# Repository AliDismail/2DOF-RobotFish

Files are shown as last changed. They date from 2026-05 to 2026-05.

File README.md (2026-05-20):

# 2-DoF Fish Robot - Kinematics Project

Robotic fish have attracted significant attention for their biomimetic design and applications in environmental monitoring, biological surveys, and underwater exploration. Unlike propeller-driven systems, which generate noise and disturb marine ecosystems, robotic fish provide efficient and less intrusive locomotion.

This project builds on the work of Wang et al. (2026) by focusing on the kinematic modeling of a wire-driven fish equipped with a 2-DoF crank-slider mechanism. The design decouples propulsion from steering, enabling both high swimming speed and agile maneuverability. While the original study employed servo-based continuous rotation control, our project simplifies the system using budget-friendly components and replaces the motor control with an encoder-based PID algorithm. This ensures smooth, accurate motion while retaining the core crank-slider actuation and robotic system architecture.

---

## Table of Contents

- [Design Analysis](#design-analysis)
  1. [Original Design Concept from the Research Paper](#1-original-design-concept-from-the-research-paper)
  2. [Description of the SolidWorks Design](#2-description-of-the-solidworks-design)
  3. [Mechanism Type and Degree of Freedom](#3-mechanism-type-and-degree-of-freedom)
  4. [Kinematic Analysis](#4-kinematic-analysis)
  5. [Material Selection](#5-material-selection)
  6. [Limitations of the Current Design](#6-limitations-of-the-current-design)
  7. [Conclusion](#7-conclusion-design-analysis)
- [Motion Control](#motion-control)
  - [Methodology and Implementation](#methodology-and-implementation)
- [Hardware and Programming Implementation](#hardware-and-programming-implementation)
- [Conclusion](#conclusion)
- [References and Links](#references-and-links)

---

## Design Analysis

In this section, we analyze the Biomimetic Fish Robot Based on a Modified 2-DoF Crank-Slider / Slotted Crank-Rocker Mechanism.

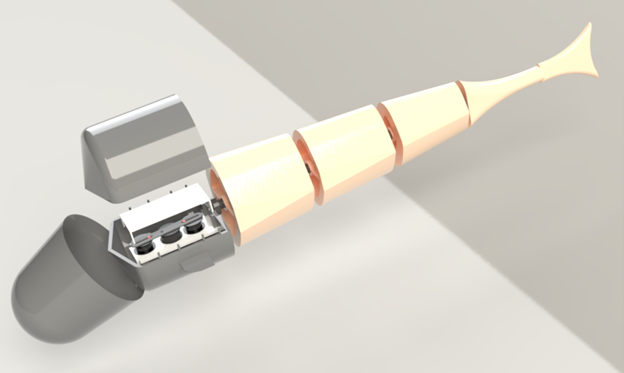
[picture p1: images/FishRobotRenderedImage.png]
Figure 1: FishRobotRenderedImaget


_Figure 1: Fish Robot Rendered Image_

### 1. Original Design Concept from the Research Paper

The original robotic fish consists of a rigid head shell, segmented rear body, elastic spine, driving wire, pectoral fins, and passive caudal fin. The rigid head contains the actuation mechanism and electronics, while the rear body bends to generate fish-like swimming motion.

The actuation mechanism in the paper contains two independently controlled driving wheels connected to a slotted rod and reel. The reel drives a wire connected to the tail. The main advantage of the mechanism is that it can operate in symmetric and asymmetric modes. In symmetric mode, both motors rotate together to produce forward propulsion. In asymmetric mode, one motor can create a mean tail offset while the other provides continuous oscillation, allowing turning motion.

The original prototype used compact DYNAMIXEL servo motors, a PLA body and head, SUS304 stainless steel linkage components, a silicone waterproof skin, and an elastic urethane spine. The paper reports that the prototype was 502 mm long, 83 mm wide, 128 mm high, and had a mass of 2050 g.

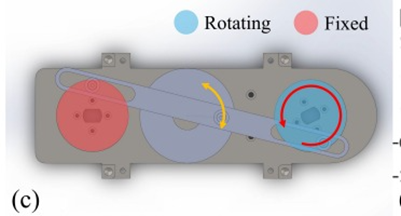
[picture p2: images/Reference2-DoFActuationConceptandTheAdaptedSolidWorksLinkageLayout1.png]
Figure 2: Reference2-DoFActuationConceptandTheAdaptedSolidWorksLinkageLayout1

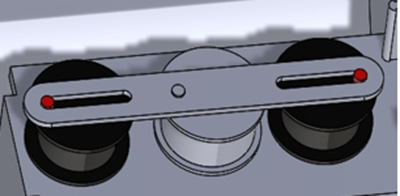
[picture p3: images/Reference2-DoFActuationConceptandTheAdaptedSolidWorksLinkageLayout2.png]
Figure 2.5: Reference2-DoFActuationConceptandTheAdaptedSolidWorksLinkageLayout2

_Figure 2: Reference 2-DoF Actuation Concept and The Adapted SolidWorks Linkage Layout_

### 2. Description of the SolidWorks Design

The SolidWorks model follows the same general fish structure as the paper but includes important changes to fit the available components. The design contains a deeper front tub, internal gears, DC motors, a slotted rocker linkage, segmented cylindrical body parts, and a tail fin. The main design focus was packaging the actuation mechanism inside the head while maintaining the external appearance of a fish.

The head tub is the main mechanical housing. It supports the motors, gears, shafts, rocker link, and cover. Since the DC motors used in this project are much taller than the servo motors in the original paper, the tub had to be significantly deeper. This modification allowed the motors to fit vertically while leaving enough clearance for the gears and moving linkage.

The final SolidWorks model has an overall length of 1051 mm, a maximum width of 190 mm, and a maximum height of 159 mm. These dimensions represent the complete assembled fish robot, including the rigid head, internal motor tub, segmented body, and caudal fin. Compared with the original paper, the overall dimensions are larger mainly because our design uses taller DC motors with encoders, which require a deeper head section to fit the motors, gears, and linkage mechanism.

The rear body was modeled as multiple streamlined segments to represent the flexible body of the fish. The caudal fin was modeled at the rear to represent the tail surface responsible for producing thrust when oscillated.

### 3. Mechanism Type and Degree of Freedom

The mechanism in the SolidWorks design is best described as a double-input slotted crank-rocker mechanism inspired by the paper's 2-DoF crank-slider system. The rotating gears or disks act as cranks. The pins on these gears slide inside elongated slots in the long central link. This long link does not rotate continuously through 360 degrees; instead, it oscillates through a limited angle. Therefore, it behaves like a rocker.

The rocker type used in this design is a slotted rocker. It is "slotted" because the crank pins move inside long slots, and it is a "rocker" because its output is limited to angular oscillation rather than full rotation.

The output of the rocker is transmitted to the elastic tail through a driving wire. One end of the wire is fixed to the reel, which is attached to the central rocker link, and the other end is fixed to the trailing section of the elastic spine. As the rocker oscillates, it winds and unwinds the wire alternately, pulling the tail from side to side and generating the oscillatory body motion required for propulsion. The wire offset distance _d_ from the spine centerline converts the reel's angular displacement directly into the tail attack angle θₐ.

In its complete actuated form, the system has two actuated degrees of freedom because it uses two independently driven motors. The motors are independently controlled — one input can affect oscillation frequency and the other can affect the mean tail angle. However, if both motors are synchronized or if one motor is fixed while the other rotates, the mechanism behaves as an effective 1-DOF mechanism during that operating condition.

The degrees of freedom of the mechanism are verified using the Kutzbach criterion:

$$M = 3(n - 1) - 2j_1 - j_2$$

where _n_ is the number of links, _j₁_ is the number of full joints (one degree of freedom each), and _j₂_ is the number of half joints (two degrees of freedom each). The mechanism consists of 5 links: the ground frame, the two driving cranks (gear disks), middle gear, and the central slotted rocker. It has 4 full joints: the two revolute joints at the motor shafts and the two pin-in-slot joints between the crank pins and the rocker slots.

Substituting:

$$M = 3(5 - 1) - 2(4) - 1(2) = 12 - 8 - 2 = 2$$

When one motor is set to a bias angle:

$$M = 3(4 - 1) - 2(3) - 1(2) = 1$$

Hence the system has **2 DoF in symmetric mode** and **1 DoF in asymmetric mode**.

### 4. Kinematic Analysis

The purpose of the internal mechanism is to convert motor rotation into oscillating tail motion. Each motor rotates a gear or disk with an offset pin. As the disk rotates, the pin follows a circular path. Since the pin is located inside a slot in the rocker, the circular motion forces the rocker to oscillate.

The operating sequence is as follows:

1. DC motors rotate the gears.
2. The gear pins move inside the rocker slots.
3. The rocker oscillates from side to side.
4. This oscillation is transmitted to the tail.

The resulting tail motion imitates the left-right tail beat of a swimming fish.

When both motors rotate together, the mechanism produces a more symmetric oscillation suitable for forward swimming. When one motor position is shifted or fixed while the other rotates, the output becomes biased to one side. This creates a mean tail angle and can be used for turning.

### 5. Material Selection

For a prototype, the head tub and body sections are manufactured using PLA because it is easy to 3D print and suitable for rapid prototyping.

For the linkage and rocker, a stronger material such as aluminum or stainless steel is preferred because these parts experience sliding contact and repeated oscillating loads. The original paper used SUS304 stainless steel for the actuation linkage, which provides good strength and corrosion resistance. Our project uses a 3D printed link due to a tight schedule.

The spine should be made from a flexible material such as rubber, silicone, TPU, or another compliant polymer.

**Table 1: Selected Part Material**

| Part | Suggested Material | Reason |
| --- | --- | --- |
| Head tub / rigid shell | PLA | Easy to 3D print, rigid, suitable for prototypes  |
| Body segments | PLA | Lightweight and simple to manufacture |
| Slotted rocker / linkage | Aluminum or SUS304 stainless steel | Higher stiffness and better wear resistance |
| Gear shafts | Steel or stainless steel | Good strength and alignment stability |
| Spine | TPU, rubber, or silicone | Flexible and suitable for oscillating tail motion |

### 6. Limitations of the Current Design

The main limitation is the large head depth caused by using tall DC motors, making the design less compact than the original and potentially reducing swimming efficiency due to increased drag.

Although the design uses DC motors equipped with encoders (which improves motion feedback), the servo motors used in the original are more accurate.

The slotted rocker mechanism may also experience friction and wear at the sliding contacts. Bearings, bushings, or low-friction inserts could improve the motion.

### 7. Conclusion (Design Analysis)

The SolidWorks model successfully recreates the main mechanical concept of the robotic fish presented in the reference paper. The design uses a double-input slotted crank-rocker mechanism inspired by the 2-DoF crank-slider actuation system. The mechanism converts rotary input from two motors into an oscillating rocker motion that can be transferred to the tail.

The largest design difference is the actuator selection. The original research prototype used compact servo motors, while this project used taller DC motors, requiring a much deeper head tub. The mechanism has 2 actuated degrees of freedom when both motors are independently controlled, but can behave as an effective 1-DOF mechanism when synchronized. Future improvements are needed in compactness, waterproofing, friction reduction, and motion validation.

---

## Motion Control

### Methodology and Implementation

The fish robot is designed based on a biomimetic actuation mechanism that converts rotational motor inputs into oscillatory tail motion. The system consists of two motor-driven cranks connected to a reel through linkages, forming a crank–slider mechanism. This configuration enables controlled deformation of a flexible tail, which generates propulsion through periodic motion (Lee et al., 2007).

Please find the detailed implementation and derivationm in the detailed report of the project.

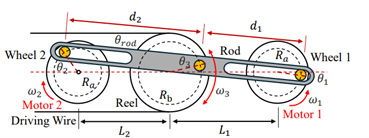
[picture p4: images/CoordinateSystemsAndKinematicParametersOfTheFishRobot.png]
Figure 3: CoordinateSystemsAndKinematicParametersOfTheFishRobot


_Figure 3: Coordinate Systems And Kinematic Parameters Of The Fish Robot_

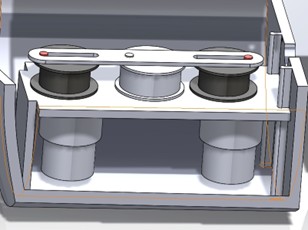
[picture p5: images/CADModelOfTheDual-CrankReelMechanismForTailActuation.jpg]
Figure 4: CADModelOfTheDual-CrankReelMechanismForTailActuation


_Figure 4: CAD Model Of The Dual-Crank Reel Mechanism For Tail Actuation_

The sign of φ (the pitch angle between the the tip of the tail and the horizental line) determines the direction of turning:

| φ value | Effect |
| --- | --- |
| φ < 0 (e.g., −π/2) | Tail biased right → robot turns right |
| φ > 0 (e.g., +π/2) | Tail biased left → robot turns left |
| φ = 0 | Reduces to symmetric case → robot swims straight |

This is consistent with the paper's experimental result, where fixing Motor 2 at −90° produced a turning radius of 0.56 m (1.12 BL), completing one full circle in 14 seconds.

---

## Hardware and Programming Implementation

### Hardware

The following components were used for the implementation:

- Arduino Nano 3.0
- Dual Channel DC Motor Driver L298N
- DC Motor with Gearbox and Encoder JGB37-520 12V 178RPM
- LiPo Battery 3S 30C 1800mAh
- 3S LiPo Battery Balance Charger
- 12V to 5V Voltage Converter

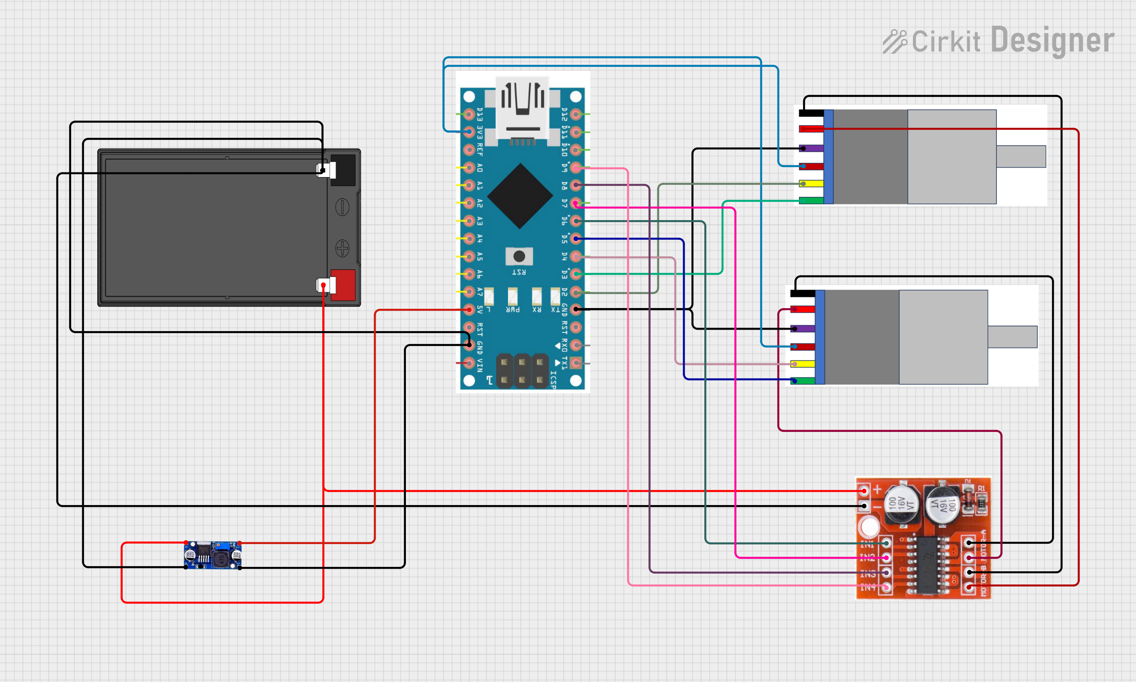
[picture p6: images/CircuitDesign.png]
Figure 5: CircuitDesign


_Figure 5: Circuit Design_

### Programming and Control Algorithm

The control algorithm is implemented on an Arduino Nano 3.0 and structured around a fixed 20 Hz interrupt-driven loop. The system reads both motor encoders at each tick, computes forward kinematics, and updates the motor controllers accordingly.

#### 1. Encoder Feedback

Each JGB37-520 motor is equipped with a Hall effect encoder rated at 20 pulses per revolution (PPR). Quadrature decoding is applied by monitoring both encoder channels on interrupt pins, yielding an effective resolution of 80 counts per revolution. From the encoder count delta over the control period ΔT:

```
θ = (counts / 80) · 2π
ω = Δcounts / (80 · ΔT) · 2π
```

#### 2. Motor 1 with Speed PID

The kinematic model treats the angular velocity of Motor 1 as a constant input ω. To enforce this at the hardware level, Motor 1 is governed by a single-loop speed PID:

```
error₁ = ω_target − ω_measured
```

The output drives the L298N PWM signal such that the measured angular velocity tracks the commanded tail-beat frequency regardless of load variation.

#### 3. Motor 2 with Cascaded Position–Speed PID

Motor 2 must hold a fixed angular position φ during asymmetric mode while the elastic spine continuously exerts a restoring torque against it. A cascaded (inner–outer) PID structure is used.

The outer loop operates on position error and outputs a commanded angular velocity:

```
error_pos = φ_target − φ_actual
ω_commanded = PID_outer(error_pos)
```

The inner loop then tracks that commanded velocity in real time:

```
error_spd = ω_commanded − ω_measured
PWM = PID_inner(error_spd)
```

This structure makes the holding behavior stiff — the inner loop actively drives the motor at whatever rate the outer loop requires, counteracting the tail load before significant position error accumulates.

#### 4. Control Modes and Sequence

The system operates in two modes:

- **Symmetric mode:** Both motors are commanded to rotate at ω speed, and Motor 2's position setpoint mirrors Motor 1's live encoder reading.
- **Asymmetric mode:** Motor 1's speed PID maintains ω while Motor 2's cascaded PID holds φ at the steering offset.

The demo sequence cycles continuously through:

> Forward swimming (3 s) → Right turn (1 s) → Forward (1 s) → Left turn (1 s)

All PID integrators are reset at each mode transition to prevent windup carry-over.

---

## References and Links

- Wang, Y., Chen, C., Chen, Y., Li, J., Motegi, Y., Ohkuma, K., Maki, T., & Zhao, M. (2026). _Design, modeling and direction control of a wire-driven robotic fish based on a 2-DoF crank-slider mechanism_. arXiv. <https://arxiv.org/abs/2603.02851>

- Lee, S., Park, J., & Han, C. (2007). Optimal control of a mackerel-mimicking robot for energy efficient trajectory tracking. _Journal of Bionic Engineering_, 4(4), 209–215. <https://doi.org/10.1016/S1672-6529(07)60029-7>

---

**Done by** Ali Ismail, Maria Al Sayed, Ghadi Ammar, and Elie Mina

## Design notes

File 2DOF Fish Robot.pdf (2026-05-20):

# Lebanese American University

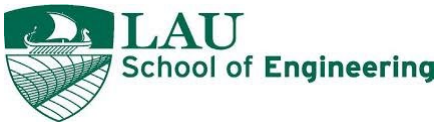
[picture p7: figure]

# MEE 342 – Kinematics of Machines

# Dr. Carine Habchi

# Kinematics Project

### Maria Al Sayed Ghadi Ammar Ali Ismail Elie Mina

04-08-2026

[Al Sayed, Ammar, Ismail, & Mina]

# Table of Contents

# Table of Tables

# Table of Figures

Figure 2: Reference 2-DoF Actuation Concept and The Adapted SolidWorks Linkage Layout .........Error! Bookmark not defined.

# Introduction

Robotic fish have attracted significant attention for their biomimetic design and applications in environmental monitoring, biological surveys, and underwater exploration. Unlike propeller-driven systems, which generate noise and disturb marine ecosystems, robotic fish provide efficient and less intrusive locomotion. This project builds on the work of Wang et al. (2026) by focusing on the kinematic modeling of a wire-driven fish equipped with a 2-DoF crank-slider mechanism. The design decouples propulsion from steering, enabling both high swimming speed and agile maneuverability. While the original study employed servo-based continuous rotation control, our project simplifies the system using budget-friendly components and replaces the motor control with an encoder based PID algorithm. This ensures smooth, accurate motion while retaining the core crank-slider actuation and robotic system architecture.

# Design Analysis

In this section, we will go through the analysis of the Biomimetic Fish Robot Based on a Modified 2-DoF Crank-Slider / Slotted Crank-Rocker Mechanism.

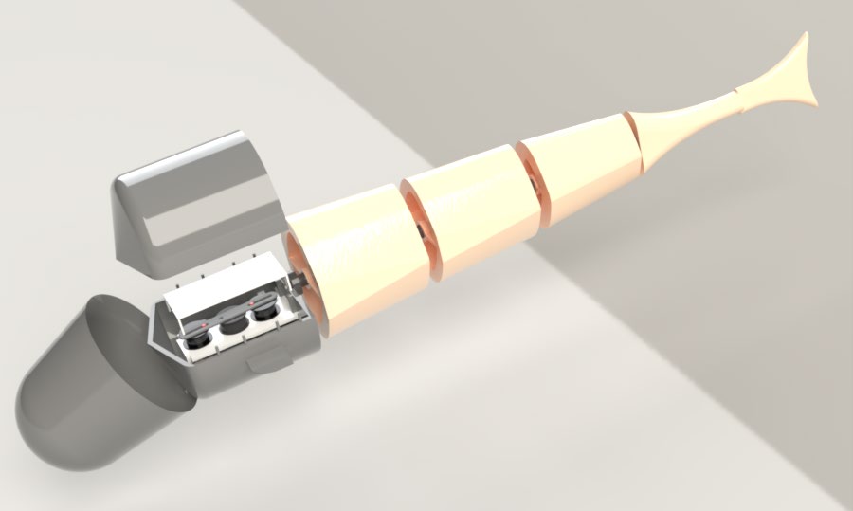
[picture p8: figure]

Figure 1: Fish Robot Rendered Image

## 1. Original Design Concept from the Research Paper

The original robotic fish consists of a rigid head shell, segmented rear body, elastic spine, driving wire, pectoral fins, and passive caudal fin. The rigid head contains the actuation mechanism and electronics, while the rear body bends to generate fish-like swimming motion.
The actuation mechanism in the paper contains two independently controlled driving wheels connected to a slotted rod and reel. The reel drives a wire connected to the tail. The main advantage of the mechanism is that it can operate in symmetric and asymmetric modes. In symmetric mode, both motors rotate together to produce forward propulsion. In asymmetric mode, one motor can create a mean tail offset while the other provides continuous oscillation, allowing turning motion.
The original prototype used compact DYNAMIXEL servo motors, a PLA body and head, SUS304 stainless steel linkage components, a silicone waterproof skin, and an elastic urethane spine. The paper reports that the prototype was 502 mm long, 83 mm wide, 128 mm high, and had a mass of 2050 g.

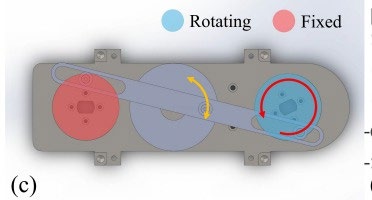
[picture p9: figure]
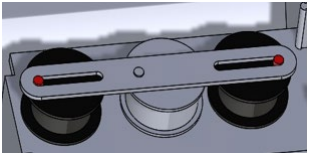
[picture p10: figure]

Figure 2: Reference 2-DoF Actuation Concept and The Adapted SolidWorks Linkage Layout

## 2. Description of the SolidWorks Design

The SolidWorks model follows the same general fish structure as the paper but includes important changes to fit the available components. The design contains a deeper front tub, internal gears, DC motors, a slotted rocker linkage, segmented cylindrical body parts, and a tail fin. The main design focus was packaging the actuation mechanism inside the head while maintaining the external appearance of a fish.
The head tub is the main mechanical housing. It supports the motors, gears, shafts, rocker link, and cover. Since the DC motors used in this project are much taller than the servo motors in the original paper, the tub had to be significantly deeper. This modification allowed the motors to fit vertically while leaving enough clearance for the gears and moving linkage.

The final SolidWorks model has an overall length of 1051 mm, a maximum width of 190 mm, and a maximum height of 159 mm. These dimensions represent the complete assembled fish robot, including the rigid head, internal motor tub, segmented body, and caudal fin. Compared with the original paper, the overall dimensions are larger mainly because our design uses taller DC motors with encoders, which require a deeper head section to fit the motors, gears, and linkage mechanism.

The rear body was modeled as multiple streamlined segments to represent the flexible body of the fish. The caudal fin was modeled at the rear to represent the tail surface responsible for producing thrust when oscillated.

## 3. Mechanism Type and Degree of Freedom

The mechanism in the SolidWorks design is best described as a double-input slotted crank-rocker mechanism inspired by the paper's 2-DoF crank-slider system. The rotating gears or disks act as cranks. The pins on these gears slide inside elongated slots in the long central link. This long link does not rotate continuously through 360 degrees; instead, it oscillates through a limited angle. Therefore, it behaves like a rocker.
The rocker type used in this design is a slotted rocker. It is "slotted" because the crank pins move inside long slots, and it is a "rocker" because its output is limited to angular oscillation rather than full rotation. The output of the rocker is transmitted to the elastic tail through a driving wire. One end of the wire is fixed to the reel, which is attached to the central rocker link, and the other end is fixed to the trailing section of the elastic spine. As the rocker oscillates, it winds and unwinds the wire alternately, pulling the tail from side to side and generating the oscillatory body motion required for propulsion. The wire offset distance d from the spine centerline converts the reel's angular displacement directly into the tail attack angle θₐ.
In its complete actuated form, the system has two actuated degrees of freedom because it uses two independently driven motors. The motors are independently controlled, one input can affect oscillation frequency and the other can affect the mean tail angle. However, if both motors are synchronized or if one motor is fixed while the other rotates, the mechanism behaves as an effective 1-DOF mechanism during that operating condition.
The degrees of freedom of the mechanism are verified using the Kutzbach criterion:
M = 3(n − 1) − 2j₁ − j₂
where n is the number of links, j₁ is the number of full joints (one degree of freedom each), and j₂ is the number of half joints (two degrees of freedom each). The mechanism consists of 5 links: the ground frame, the two driving cranks (gear disks), middle gear, and the central slotted rocker. It has 4 full joints: the two revolute joints at the motor shafts and the two pin-in-slot joints between the crank pins and the rocker slots. The pin-in-slot joint allows both rotation and sliding simultaneously, making it a full joint with 2 relative motions, which counts as a half joint j₂ in the Kutzbach formula. Substituting:
M = 3(5 − 1) − 2(4) − 1(2) = 12 − 8 − 2 = 2 This gives M = 2 for a dual-input system. When we set one of the motors on a bias angle. The mechanism therefore has:
M = 3(4 − 1) − 2(3) − 1(2) = 1 Hence the system will have 2 DoF in symmetric mode and 1 DoF in asymmetric mode.

## 4. Kinematic Analysis

The purpose of the internal mechanism is to convert motor rotation into oscillating tail motion. Each motor rotates a gear or disk with an offset pin. As the disk rotates, the pin follows a circular path. Since the pin is located inside a slot in the rocker, the circular motion forces the rocker to oscillate.

The operating sequence is the DC motors rotate the gears, the gear pins move inside the rocker slots, the rocker oscillates from side to side, and this oscillation can be transmitted to the tail. The resulting tail motion imitates the left-right tail beat of a swimming fish.
When both motors rotate together, the mechanism produces a more symmetric oscillation suitable for forward swimming. When one motor position is shifted or fixed while the other rotates, the output becomes biased to one side. This creates a mean tail angle and can be used for turning.

## 5. Material Selection

For a prototype, the head tub and body sections are manufactured using PLA because it is easy to 3D print and suitable for rapid prototyping.
For the linkage and rocker, a stronger material such as aluminum or stainless steel is preferred because these parts experience sliding contact and repeated oscillating loads. The original paper used SUS304 stainless steel for the actuation linkage, which is suitable because it provides good strength and corrosion resistance. But we have a 3D printed link due to a tight schedule.
The spine should be made from a flexible material such as rubber, silicone, TPU, or another compliant polymer. Table 1 summarizes the suggested material choices for the main parts of the design.

Table 1: Selected Part Material
Part | Suggested Material | Reason
Head tub / rigid shell | PLA | Easy to 3D print, rigid, suitable for prototypes
Body segments | PLA | Lightweight and simple to manufacture
Slotted rocker / linkage | Aluminum or SUS304 stainless steel | Higher stiffness and better wear resistance
Gear shafts | Steel or stainless steel | Good strength and alignment stability
Spine | TPU, rubber, or silicone | Flexible and suitable for oscillating tail motion

## 6. Limitations of the Current Design

The main limitation is the large head depth caused by using tall DC motors. This makes the design less compact than and may reduce swimming efficiency due to increased drag.
Another limitation is that although the design uses DC motors, they are equipped with encoders, which improves motion feedback and allows the motor position and speed to be monitored. This makes the system more controllable than a basic DC motor setup. However, the servo motors used in the original are more accurate.
The slotted rocker mechanism may also experience friction and wear at the sliding contacts. Bearings, bushings, or low-friction inserts could improve the motion.

## 7. Conclusion

The SolidWorks model successfully recreates the main mechanical concept of the robotic fish presented in the reference paper. The design uses a double-input slotted crank-rocker mechanism inspired by the 2-DoF crank-slider actuation system. The mechanism converts rotary input from two motors into an oscillating rocker motion that can be transferred to the tail.
The largest design difference is the actuator selection. The original research prototype used compact servo motors, while this project used taller DC motors. Because of this, the head tub had to be made much deeper to fit the motors, gears, shafts, and linkage. This caused the final dimensions of the design to differ significantly from the original paper.
The mechanism can be described as having 2 actuated degrees of freedom when both motors are independently controlled. However, it can behave as an effective 1 DOF mechanism when the motors are synchronized or when one motor is fixed. Overall, the design demonstrates a practical mechanical adaptation of the paper’s fish robot concept, with future improvements needed in compactness, waterproofing, friction reduction, and motion validation.

# Motion Control

## Methodology and Implementation

### 1. System Overview

The fish robot is designed based on a biomimetic actuation mechanism that converts rotational motor inputs into oscillatory tail motion. The system consists of two motor-driven cranks connected to a reel through linkages, forming a crank–slider mechanism. This configuration enables controlled deformation of a flexible tail, which generates propulsion through periodic motion (Lee et al., 2007).

### 2. Forward Kinematics Derivation

The objective of forward kinematics is to compute the reel angle θθ3from the known motor angles θθ1and θθ2.

Coordinate Representation
The positions of the mechanism components are defined as:
xx1 = Ra cos θθ1 + LL1 + LL2, yy1 = Ra sin θθ1 | (1)
xx2 = Ra cos θθ2 , yy2 = Ra sin θθ2 | (2)
xx3 = Rb cos θθ3 + LL2, yy3 = Rb sin θθ3 | (3)

Collinearity Constraint
The linkage points must remain collinear:

# yy2 − yy3 xx2 − xx3

# = yy1 − yy3 xx1 − xx3

(4)

Substituting:

# RRaasin θθ2 − RRbbsin θθ3

# RRaacos θθ2 − (RRbbcos θθ3 + LL2) = RRaasin θθ1 − RRbbsin θθ3 (RRaacos θθ1 + LL1 + LL2) − (RRbbcos θθ3 + LL2) (5)

Rearranged Form

By expanding Eq. (5) and grouping terms involving sin θθ3and cos θθ3, the expression can be rearranged

into a linear trigonometric form. After expansion and simplification using trigonometric identities, the equation is reduced to:

# AA cos θθ3 + BB sin θθ3 = CC (6)

where:

A = RaRb(cos θθ1 − cos θθ2) + Rb(LL1 + LL2) | (7)
BB = RRaaRRbb(sin θθ2 − sin θθ1) | (8)

# CC = RRaa

# 2 sin(θθ1 − θθ2) − RRaa(sin θθ1LL2 + sin θθ2LL1) (9)

Closed-Form Solution

# θθ3 = arcsin CC

# √AA2+BB2 − atan 2(BB, AA) (10)

This transformation allows the nonlinear geometric constraint to be solved analytically using trigonometric identities, avoiding iterative numerical methods, in addition it allows direct computation of the reel angle, making it suitable for real-time embedded implementation (Lee et al., 2007).

### 3. Tail Kinematics

The tail is modeled as a constant curvature arc:

# θa = Rb

dd θθ3 | (11)

# xx = LL

θθaa

# sin θθaa , yy = LL

θθaa

# (1 − cos θθaa) (12)

For small θθaa, a linear approximation is used to maintain numerical stability.

### 4. Implementation

The analytical model was implemented on an embedded system using Arduino. The forward kinematics equations are directly translated into code:

A validity check ensures that the computed configuration is physically feasible:

The tail position is computed as:

### 5. Velocity Estimation and Propulsion

The reel angular velocity is approximated numerically:
θθ̇

# 3 ≈ θθ3(tt) − θθ3(tt − Δtt)

Δtt | (13)

The tail-tip lateral velocity is computed using:

# vvtip =∣

LL
θθaa

# 2 (sin θa − θa cos θa)θ̇

aa ∣ (14)

The swimming speed is then estimated using a proportional model:

# vvrobot = kkthrust ⋅ vvtip (15)

### 6. Results and Interpretation

The implementation produces periodic oscillatory motion of the tail, resulting in a stable forward swimming velocity. The symmetric mode generates balanced lateral motion, confirming that the robot moves in a straight line without directional bias.
The results demonstrate that the derived kinematic model is consistent with the expected behavior of a biomimetic fish robot.

### 7. Discussion

The model successfully integrates kinematics and motion generation; however, several simplifications are present:
- Hydrodynamic effects are not explicitly modeled
- The propulsion model is simplified and experimentally tuned
- The tail is approximated as a constant curvature arc
- Numerical differentiation introduces approximation error
Despite these limitations, the model provides a computationally efficient framework for simulating robotic fish motion.

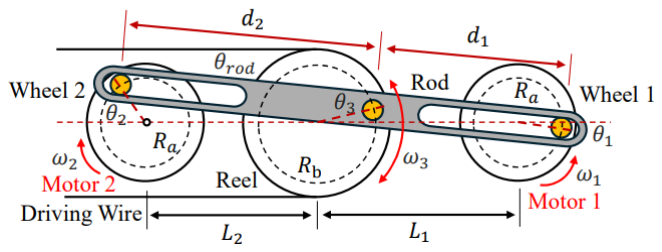
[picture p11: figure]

Figure 3: Coordinate systems and kinematic parameters of the fish robot

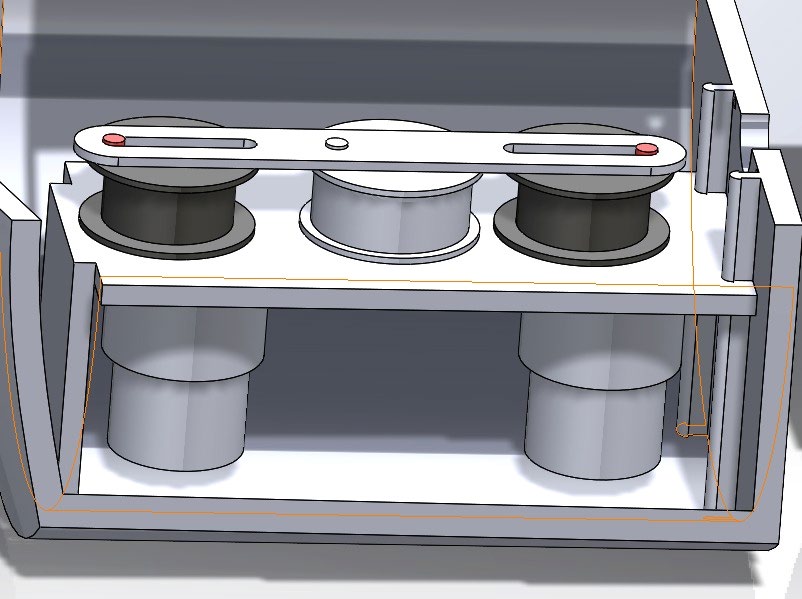
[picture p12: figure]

Figure 4: CAD Model of the Dual-Crank Reel Mechanism for Tail Actuation

## Symmetric Motion Case (Forward Motion)

In the implemented test case, both motor angles are set equal (θθ1 = θθ2), corresponding to a symmetric

actuation mode. Under this condition, the forward kinematics equations simplify significantly. From the definitions:

# A = RaRb(cos θθ1 − cos θθ2) + Rb(LL1 + LL2),B = RaRb(sin θθ2 − sin θθ1) (16)

since θθ1 = θθ2, it follows that:

# cos θθ1 − cos θθ2 = 0, sin θθ2 − sin θθ1 = 0 (17)

Thus, reducing the expressions to:

# AA = RRbb(LL1 + LL2), BB = 0 (18)

This simplification indicates that the mechanism operates in a symmetric configuration, where both sides of the system move identically. As a result, the generated motion produces a balanced tail deformation, leading to straight-line swimming behavior. This mode is typically used for forward propulsion, as it avoids lateral bias in the motion of the tail.

## Non-symmetric Motion Case (Turning Motion)

In the asymmetric mode, the two motors operate under different conditions: Motor 1 rotates continuously at angular velocity ω, while Motor 2 is held fixed at a constant angle θ₂ = φ, where φ is a chosen steering offset. The reel angle θ₃ therefore becomes a function of both the fixed position φ and the rotating input ω·t:

# [θθ3, θθ˙3] = ff2(φφ, ωω)

### 1. Reduction of the Collinearity Constraint

Returning to the general closed-form coefficients derived in the Forward Kinematics section (Equations 7–9), and substituting θ₂ = φ while letting θ₁ = ω·t:

AA = RRaaRRbb(cccccc(ωω ) − cccccc ) + RRbb(LL1 + LL2) | (19)
BB = RRaaRRbb ssss − ssss(ωω ) | (20)

# CC = RRaa

# 2 ssss(ωω − φφ) − RRaa( ssss(ωω )LL2 + ssss LL1) (21)

like the symmetric case, A and B oscillate with time as Motor 1 rotates. This means the reel angle θ₃ oscillates about a non-zero mean angle determined by φ. The reel angle is still obtained from Equation (10):

# θθ3 = arcsin CC √AA2 + BB2

# − atan(BB, AA) (22)

### 2. Mean Oscillation Angle

Fixing Motor 2 at φ ≠ 0 introduces a DC bias into the reel oscillation. To visualize this, consider that when φ = 0 the mechanism is symmetric and θ₃ oscillates symmetrically about zero, producing a straight tail trajectory. When φ ≠ 0, the midpoint of the reel's oscillation shifts away from zero. The mean tail

deflection θθ3
− angle follows from Equation (11):

θθaa

# − = RRbb

## dd θθ3

− | (23)

where θθ3
− is the time-averaged reel angle over one full rotation of Motor 1. A positive φ shifts the mean

tail deflection to one side, generating a lateral force imbalance that causes the robot to turn.

### 3. Decoupling of Propulsion and Steering

This mode achieves the central design goal of the 2-DoF mechanism: propulsion and steering are controlled by independent inputs.

- Motor 1 (rotating at ω): controls the oscillation frequency and thus the tail-beat speed and forward thrust, independently of direction.
- Motor 2 (fixed at φ): controls the mean oscillation angle of the tail, and thus the turning direction and radius, independently of speed.
The swimming speed and yaw direction of the robot can therefore be expressed jointly as:

# vvrrrr rrrr, ψψrrrr rrrr] = gg2(θθ3, θθ˙3) = gg2(ff2(φφ, ωω)) (24)

where g₂ is the same propulsion mapping used in the symmetric case (Equations 14–15), now evaluated on the asymmetric reel output.
Turn Direction
The sign of φ determines the direction of the bias and therefore the direction of turning:
- φ < 0 (e.g., φ = −π/2): the tail is biased toward the right side of the body → the robot turns right
- φ > 0 (e.g., φ = +π/2): the tail is biased toward the left side of the body → the robot turns left
- φ = 0: reduces to the symmetric case (Equation 18), and the robot swims straight
This relationship is consistent with the paper's experimental result, where fixing Motor 2 at −90° produced a turning radius of 0.56 m (1.12 BL) completing one full circle in 14 seconds.

# Hardware and Programing Implementation

## Hardware

For the implementation of the robot, we decided to use:
- Arduino nano 3.0
- Dual Channel DC Motor Driver L298N
- DC Motor with Gearbox and Encoder JGB37-520 12V 178RPM
- Lipo Battery 3S 30C 1800mAh
- 3S Lipo Battery Balance Charger
- 12V to 5V voltage converter
The following is the circuit diagram for the robot.

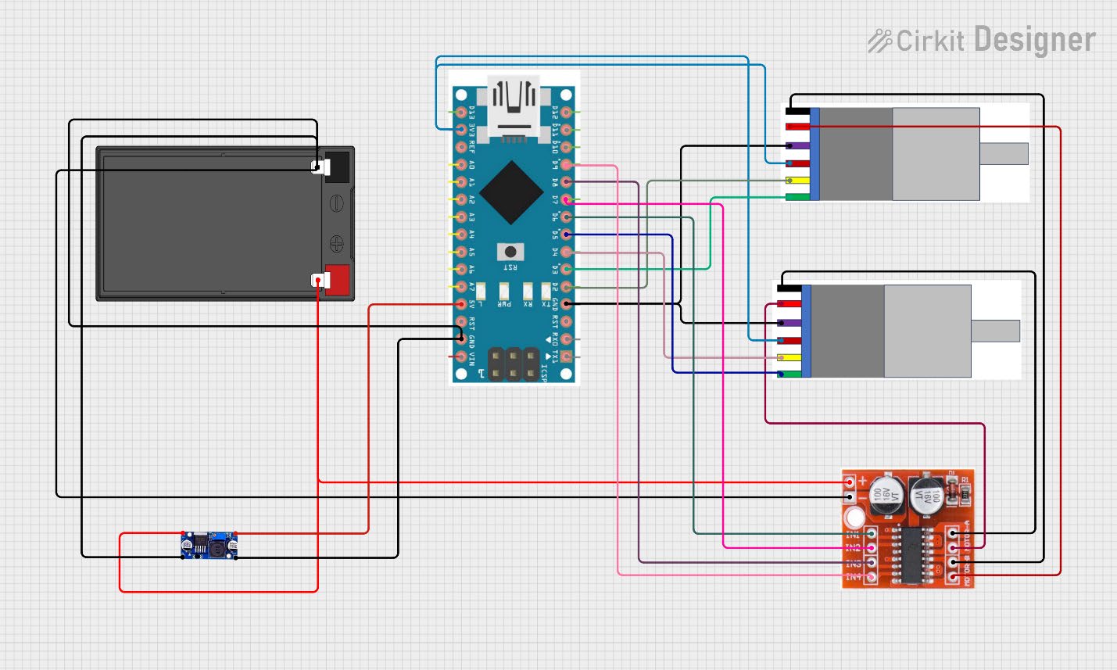
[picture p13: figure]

Figure 5: Circuit Design

## Programing and Control Algorithm

The control algorithm is implemented on an Arduino nano 3.0 and structured around a fixed 20 Hz interrupt-driven loop. The system reads both motor encoders at each tick, computes forward kinematics, and updates the motor controllers accordingly.

### 1. Encoder Feedback

Each JGB37-520 motor is equipped with a Hall effect encoder rated at 20 pulses per revolution (PPR). Quadrature decoding is applied by monitoring both encoder channels on interrupt pins, yielding an effective resolution of 80 counts per revolution. From the encoder count delta over the control period ΔT, the angular position θ and angular velocity ω of each motor are derived as:
θ = (counts / 80) · 2π
ω = Δcounts / (80 · ΔT) · 2π

### 2. Motor 1 with Speed PID

The kinematic model of Wang et al. (2026) treats the angular velocity of Motor 1 as a constant input ω. This assumption breaks down in practice when the motor slows under load, directly corrupting the FK computation and the swimming speed estimate. To enforce the constant-ω assumption at the hardware level, Motor 1 is governed by a single-loop speed PID:

error1 = ωtarget − ωmeasured
The output drives the L298N PWM signal such that the measured angular velocity tracks the commanded tail-beat frequency regardless of load variation.

### 3. Motor 2 with Cascaded Position–Speed PID

Motor 2 must hold a fixed angular position φ during asymmetric mode while the elastic spine continuously exerts a restoring torque against it. A single position loop reacts to the resulting angular displacement only after the error has already grown, producing sluggish and oscillatory holding behavior. To address this, a cascaded (inner–outer) PID structure is used.
The outer loop operates on position error and outputs a commanded angular velocity:

errorpos = φtarget − φactual

ωcommanded = PIDouter(errorpos)
The inner loop then tracks that commanded velocity in real time:

errorspd = ωcommanded − ωmeasured
PWM = PIDinner(errorspd)
This structure makes the holding behavior stiff — the inner loop actively drives the motor at whatever rate the outer loop requires, counteracting the tail load before significant position error accumulates. The inner speed loop must be tuned to stability first, after which the outer position loop is tuned on top of it.

### 4. Control Modes and Sequence

The system operates in two modes derived directly from the kinematic analysis. In the symmetric mode, both motors are commanded to rotate at ω speed, and Motor 2's position setpoint mirrors Motor 1's live encoder reading. In the asymmetric mode, Motor 1's speed PID maintains ω while Motor 2's cascaded PID holds φ at the steering offset. The demo sequence cycles through forward swimming (3 s) → right turn (1 s) → forward (1 s) → left turn (1 s), repeating continuously. All PID integrators are reset at each mode transition to prevent windup carry-over from the previous step.

# Conclusion

This project extends the kinematic framework of Wang et al. (2026) while simplifying the hardware and control system for practical implementation. By retaining the 2-DoF crank-slider mechanism, propulsion and steering remain decoupled, ensuring both speed and maneuverability. The replacement of servo-based control with an encoder driven PID algorithm provides smooth and accurate motion using accessible, budget-friendly components. Overall, the work demonstrates that effective robotic fish locomotion can be achieved with streamlined design choices, making advanced biomimetic systems more reproducible and adaptable for future research and applications.

# References and Links

- Wang, Y., Chen, C., Chen, Y., Li, J., Motegi, Y., Ohkuma, K., Maki, T., & Zhao, M. (2026). Design, modeling and direction control of a wire-driven robotic fish based on a 2-DoF crank-slider mechanism. arXiv. https://arxiv.org/abs/2603.02851
- Lee, S., Park, J., & Han, C. (2007). Optimal control of a mackerel-mimicking robot for energy efficient trajectory tracking. Journal of Bionic Engineering, 4(4), 209–215. https://doi.org/10.1016/S1672-6529(07)60029-7
- https://dynamic.me/arduino-nano-30-ch340-chip
- https://dynamic.me/dual-channel-dc-motor-driver-pwm-speed-h-bridge-stepper-l298n
- https://dynamic.me/dc-motor-with-gearbox-and-encoder-jgb-37-520-12-v-178-rpm
- https://electroslab.com/products/lipo-battery-3s-30c-1800mah?_pos=4&_sid=d1ff38652&_ss=r
- https://electroslab.com/products/3s-lipo-battery-balance-charger?_pos=5&_sid=d1ff38652&_ss=r
- https://dynamic.me/dc-to-dc-buck-converter-regulator-12-v-to-5-v-3-a-15-w

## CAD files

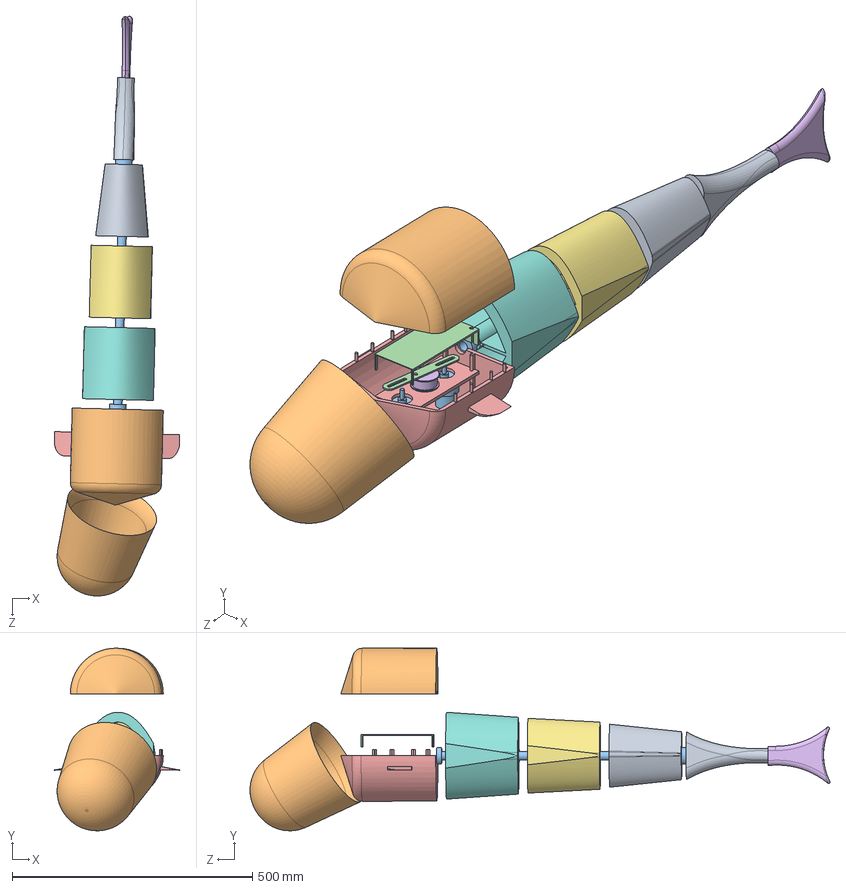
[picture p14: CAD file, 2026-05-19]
design/Assembley.SLDASM
260.8 x 380.4 x 1208.1 mm
Gear B Fish
Scratch Fish Bottom Plate
Link
DC Motor x 2
Fish Tub Upper
Spine 3
Spine 1
Spine 2
Fin
Fish Tub
Components plate
Spine Tube
fishHead
Spine42

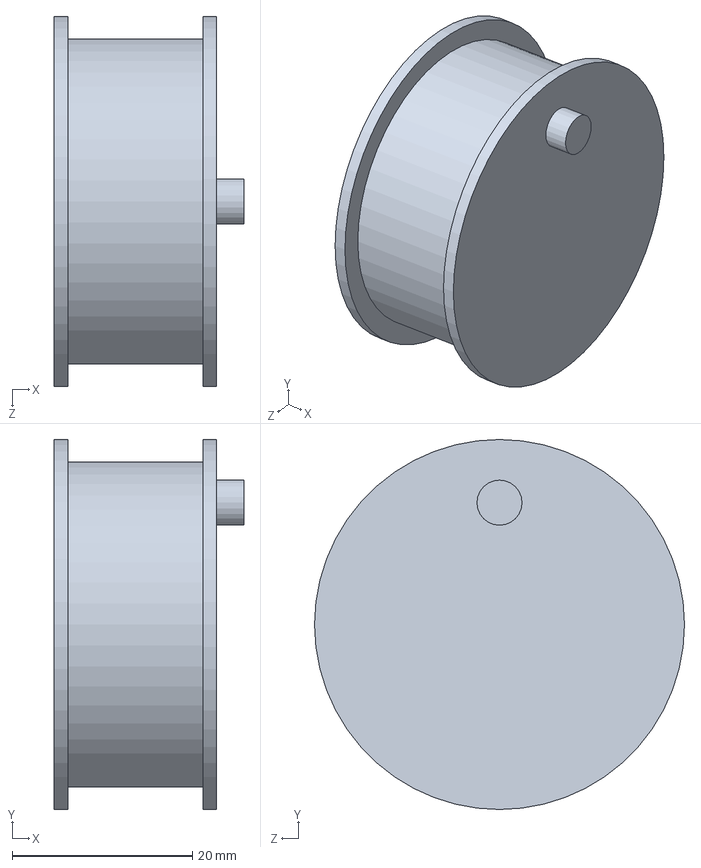
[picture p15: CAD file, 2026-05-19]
design/Gear B Fish.SLDPRT
21.0 x 41.0 x 41.0 mm

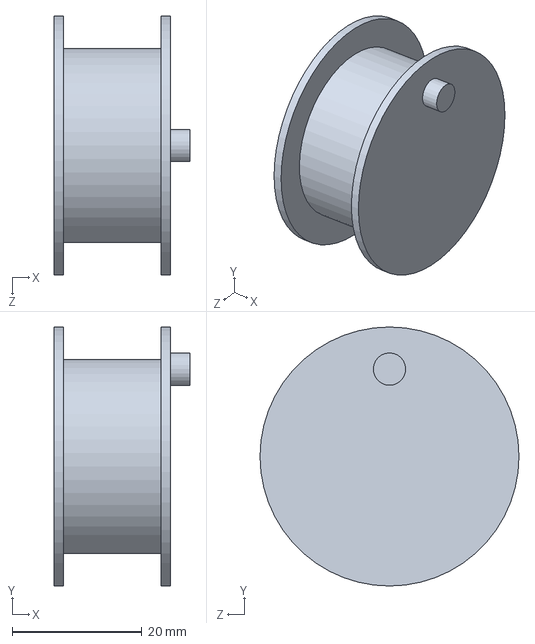
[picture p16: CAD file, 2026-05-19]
design/Gear A Fish.SLDPRT
21.0 x 40.0 x 40.0 mm

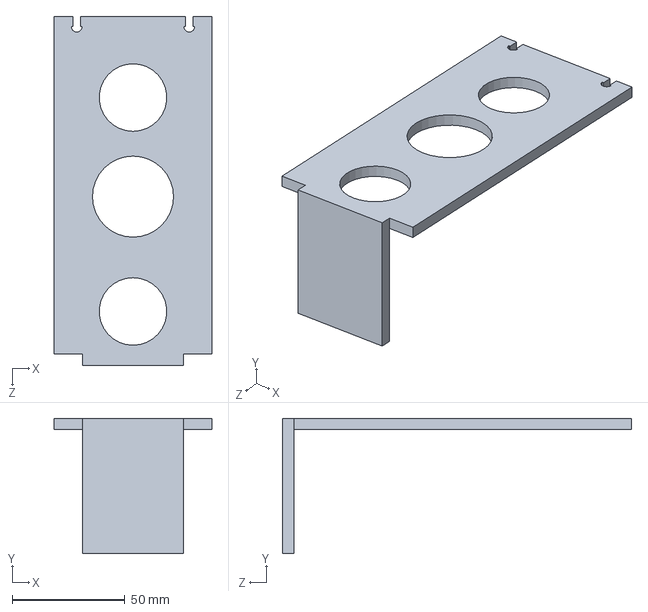
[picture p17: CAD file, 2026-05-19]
design/Scratch Fish Bottom Plate.SLDPRT
70.0 x 60.0 x 155.0 mm

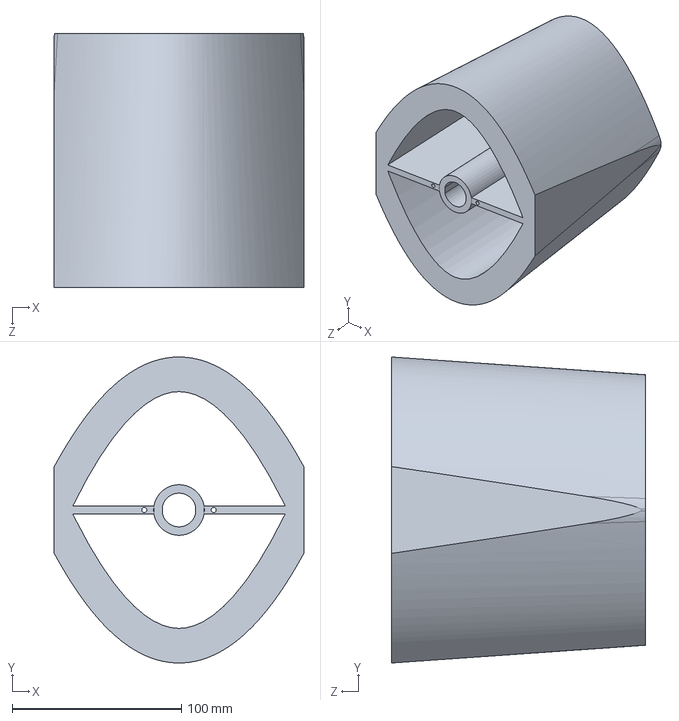
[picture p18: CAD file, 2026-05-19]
design/Spine 1.SLDPRT
147.6 x 181.0 x 150.0 mm

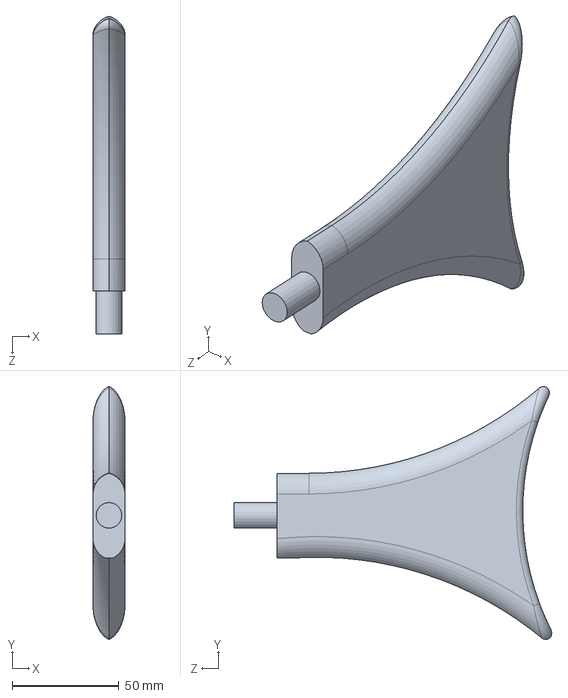
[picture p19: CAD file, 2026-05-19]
design/Fin.SLDPRT
15.0 x 118.5 x 148.8 mm

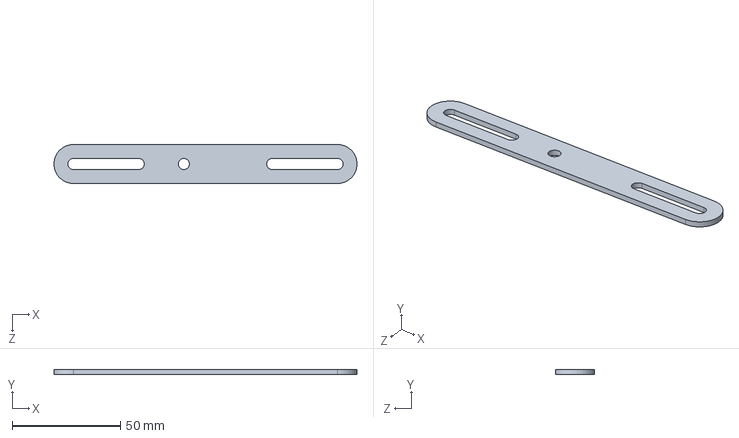
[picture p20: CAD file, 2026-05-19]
design/Link.SLDPRT
139.9 x 2.25 x 18.0 mm

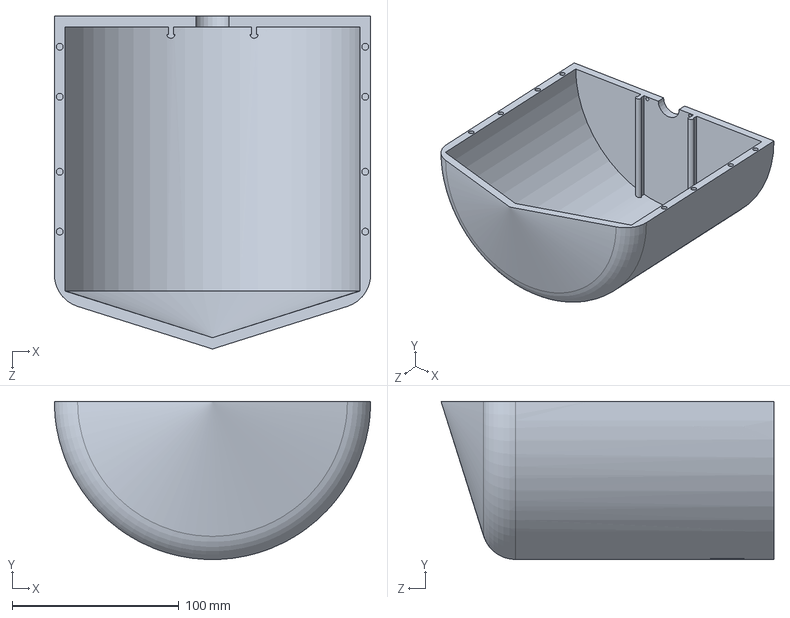
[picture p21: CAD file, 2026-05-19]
design/Fish Tub Upper.SLDPRT
190.0 x 95.0 x 200.0 mm

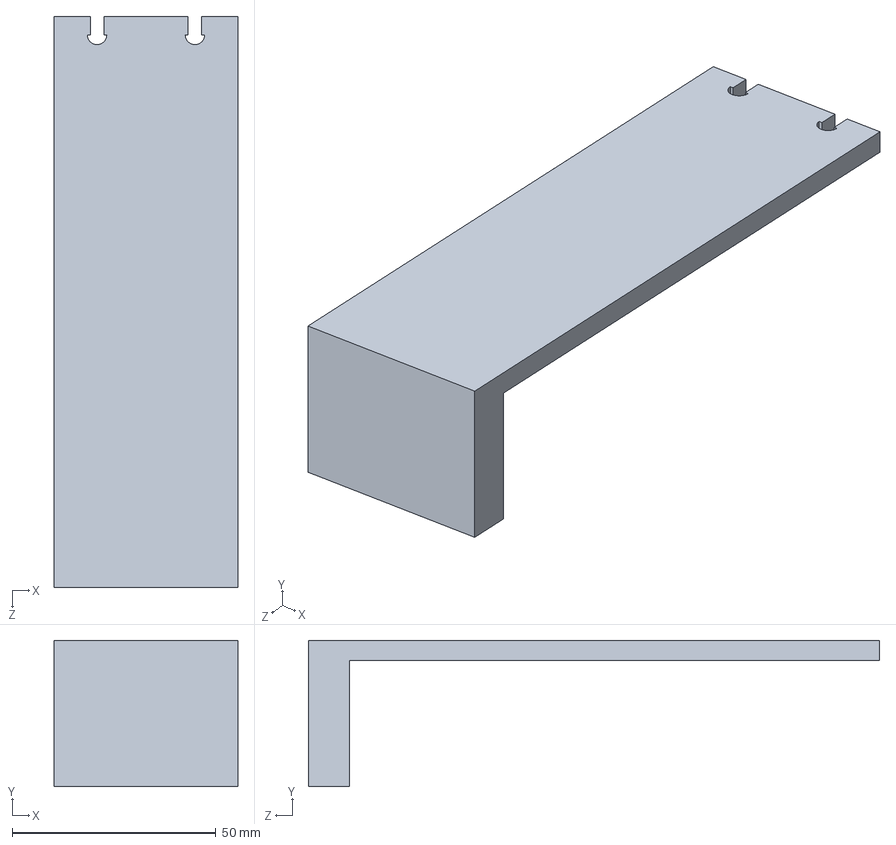
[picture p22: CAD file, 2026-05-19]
design/Fish Bottom Plate.SLDPRT
45.0 x 35.9 x 140.0 mm

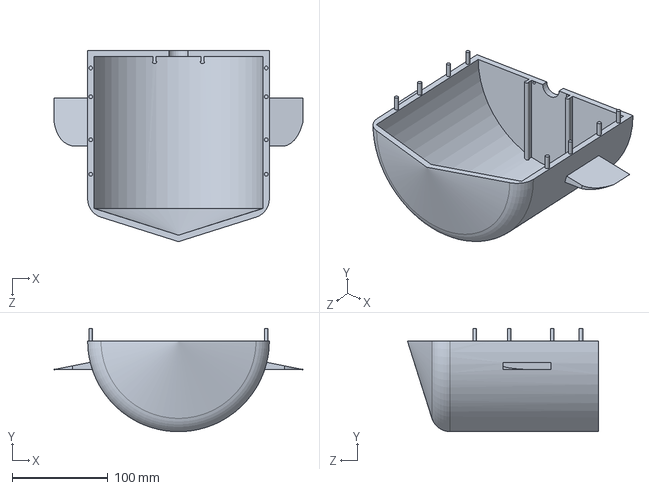
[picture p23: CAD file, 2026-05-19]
design/Fish Tub.SLDPRT
260.3 x 107.9 x 200.0 mm

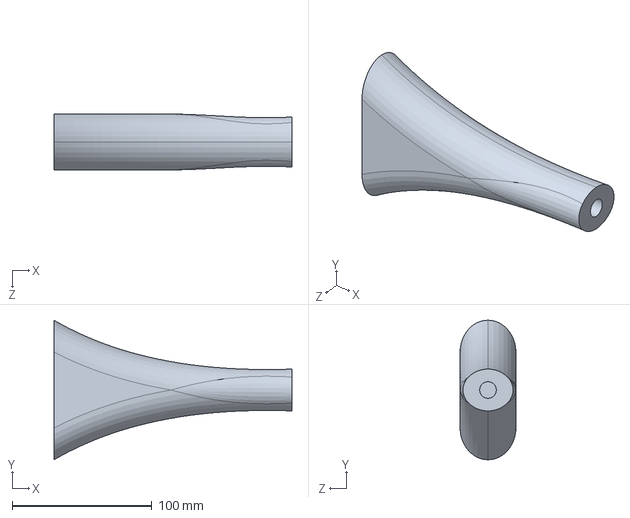
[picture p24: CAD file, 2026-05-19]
design/Spine42.SLDPRT
170.5 x 100.0 x 40.0 mm

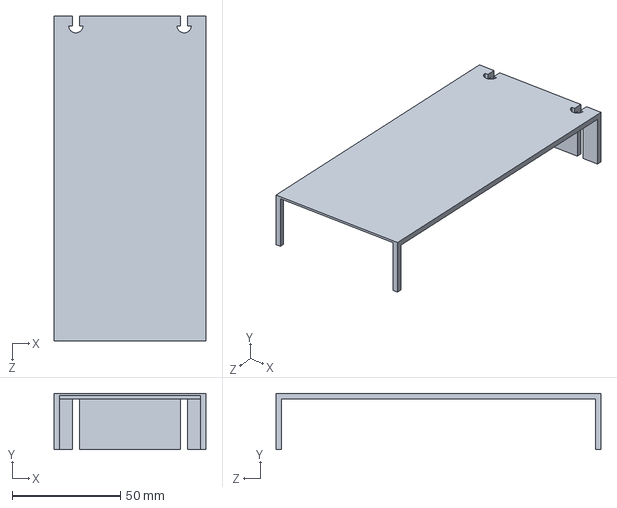
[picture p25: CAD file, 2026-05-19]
design/Components plate.SLDPRT
70.0 x 26.0 x 150.0 mm

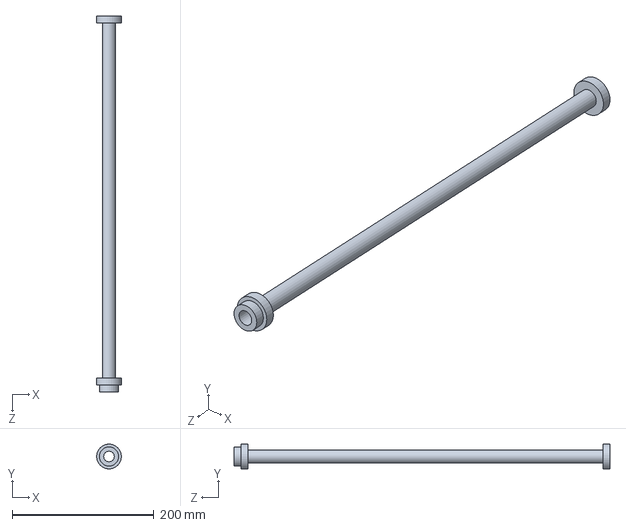
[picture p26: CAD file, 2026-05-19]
design/Spine Tube.SLDPRT
35.0 x 35.0 x 530.0 mm

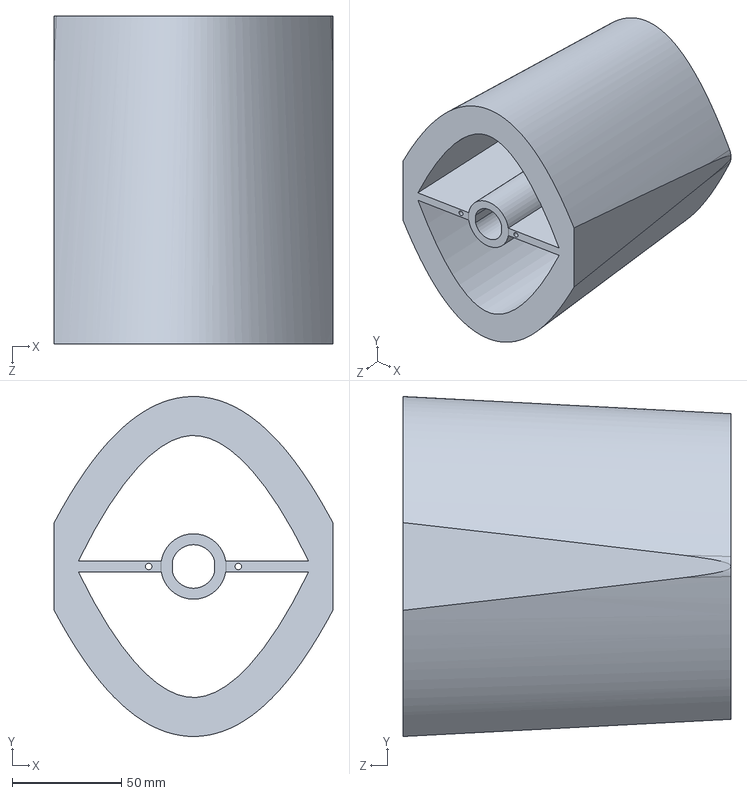
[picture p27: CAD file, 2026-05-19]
design/Spine 2.SLDPRT
127.7 x 155.7 x 150.0 mm

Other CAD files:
design/Spine 3.SLDPRT
design/DC Motor.SLDPRT
design/fishHead.SLDPRT
design/Spine 4.SLDPRT
design/Gear A Fish2.SLDPRT

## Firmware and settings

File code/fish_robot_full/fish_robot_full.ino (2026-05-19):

// ============================================================
//  FISH ROBOT — Full Control System
//  Based on Wang et al. 2-DoF Crank-Slider Paper
//
//  Includes:
//    • Forward Kinematics (Eq. 2a–2d)
//    • Symmetric Mode   → forward swimming  (Eq. 5 / 22)
//    • Asymmetric Mode  → turning           (Eq. 6 / 23)
//    • Motor 1: Speed PID  (ω = constant assumption from paper)
//    • Motor 2: Cascaded Position → Speed PID  (robust hold against tail load)
//    • Demo sequence: fwd 3s → right 1s → fwd 1s → left 1s → repeat
// ============================================================

#include <Arduino.h>

// ─────────────────────────────────────────────
//  MECHANISM GEOMETRY  (mm / radians)
// ─────────────────────────────────────────────
const float Ra       = 15.0;   // wheel radius (mm)
const float Rb       = 20.0;   // reel radius  (mm)
const float L1       = 45.0;   // motor 1 lateral offset (mm)
const float L2       = 45.0;   // motor 2 lateral offset (mm)
const float d_wire   = 10.0;   // wire offset from spine centerline (mm)
const float L_body   = 200.0;  // elastic tail length (mm)
const float k_thrust = 0.15;   // speed model constant

// ─────────────────────────────────────────────
//  MOTOR 1 PINS  (continuously rotating — propulsion)
// ─────────────────────────────────────────────
const int M1_ENA = 9;    // PWM
const int M1_IN1 = 8;
const int M1_IN2 = 7;
const int ENC1_A = 2;    // interrupt pin
const int ENC1_B = 4;

// ─────────────────────────────────────────────
//  MOTOR 2 PINS  (cascaded position+speed — steering)
// ─────────────────────────────────────────────
const int M2_ENA = 10;   // PWM
const int M2_IN1 = 12;
const int M2_IN2 = 11;
const int ENC2_A = 3;    // interrupt pin
const int ENC2_B = 5;

// ─────────────────────────────────────────────
//  ENCODER CONSTANTS
//  JGB37-520: 20 PPR Hall effect x4 quadrature = 80 counts/rev
// ─────────────────────────────────────────────
const float PPR            = 20.0;
const float COUNTS_PER_REV = PPR * 4.0;

volatile long enc1Count = 0;
volatile long enc2Count = 0;
volatile long enc1Prev  = 0;
volatile long enc2Prev  = 0;

void enc1ISR() {
  enc1Count += (digitalRead(ENC1_A) == HIGH)
                 ? (digitalRead(ENC1_B) == LOW  ? 1 : -1)
                 : (digitalRead(ENC1_B) == HIGH ? 1 : -1);
}
void enc2ISR() {
  enc2Count += (digitalRead(ENC2_A) == HIGH)
                 ? (digitalRead(ENC2_B) == LOW  ? 1 : -1)
                 : (digitalRead(ENC2_B) == HIGH ? 1 : -1);
}

float countsToRad(long counts) {
  return (float)counts / COUNTS_PER_REV * TWO_PI;
}
float deltaToRadPerSec(long delta, float dt) {
  return ((float)delta / COUNTS_PER_REV * TWO_PI) / dt;
}

// ─────────────────────────────────────────────
//  PID STRUCT
// ─────────────────────────────────────────────
struct PID {
  float Kp, Ki, Kd;
  float integral;
  float prevError;
  float iMax;
};

int computePID(PID &pid, float error, float dt) {
  pid.integral += error * dt;
  pid.integral  = constrain(pid.integral, -pid.iMax, pid.iMax);
  float derivative = (error - pid.prevError) / dt;
  pid.prevError    = error;
  float output = pid.Kp * error + pid.Ki * pid.integral + pid.Kd * derivative;
  return (int)constrain(output, -255, 255);
}

void resetPID(PID &pid) {
  pid.integral  = 0.0;
  pid.prevError = 0.0;
}

// ─────────────────────────────────────────────
//  MOTOR 1 — SPEED PID
//  Maintains constant omega so kinematic model assumption holds.
//  Error = target omega - measured omega  (rad/s)
// ─────────────────────────────────────────────
//  Tuning: raise Kp until speed oscillates, halve it.
//          add Ki slowly to eliminate steady-state lag.
//          add Kd only if overshoot on speed steps.
PID pid1_spd = { 1.5, 0.8, 0.05, 0.0, 0.0, 150.0 };

// ─────────────────────────────────────────────
//  MOTOR 2 — CASCADED POSITION (outer) + SPEED (inner) PID
//
//  Outer loop: position error (rad) → commanded speed (rad/s)
//  Inner loop: speed error   (rad/s) → PWM output
//
//  Why cascaded: the elastic spine pushes back against Motor 2's
//  fixed angle phi. A position-only PID holds the angle but reacts
//  sluggishly. The inner speed loop ensures the motor actively
//  drives at whatever rate the outer loop commands, making the
//  hold stiff and the mode transition smooth.
//
//  Tuning order (critical): tune inner speed loop first to
//  stability, THEN tune outer position loop on top of it.
// ─────────────────────────────────────────────
PID pid2_pos = { 8.0, 0.5,  0.2,  0.0, 0.0, PI     };  // outer: rad → rad/s
PID pid2_spd = { 2.0, 1.0,  0.05, 0.0, 0.0, 150.0  };  // inner: rad/s → PWM

// Maximum speed the outer loop is allowed to command (rad/s)
const float M2_MAX_CMD_SPEED = TWO_PI * 6.0;

// ─────────────────────────────────────────────
//  TIMING
// ─────────────────────────────────────────────
const int   PID_INTERVAL_MS = 50;
const float DT              = PID_INTERVAL_MS / 1000.0;

// ─────────────────────────────────────────────
//  KINEMATICS STATE
// ─────────────────────────────────────────────
float t        = 0.0;
float th3_prev = 0.0;

// ─────────────────────────────────────────────
//  DEMO SEQUENCE
// ─────────────────────────────────────────────
const float FORWARD_OMEGA = TWO_PI * 1.0;
const float TURN_THETA2_R = -PI / 2.0;
const float TURN_THETA2_L = +PI / 2.0;
const float TURN_OMEGA    = TWO_PI * 1.0;

struct Step { uint8_t mode; unsigned long dur; };
const Step SEQUENCE[] = {
  { 0, 3000 },
  { 1, 1000 },
  { 0, 1000 },
  { 2, 1000 },
};
const int SEQ_LEN = sizeof(SEQUENCE) / sizeof(SEQUENCE[0]);

int           seqIdx      = 0;
unsigned long stepStart   = 0;
uint8_t       currentMode = 0;

// ─────────────────────────────────────────────
//  FORWARD KINEMATICS  (Eq. 2a-2d)
// ─────────────────────────────────────────────
bool forwardKinematics(float th1, float th2, float &th3) {
  float A = Ra * Rb * (cos(th1) - cos(th2)) + Rb * (L1 + L2);
  float B = Ra * Rb * (sin(th2) - sin(th1));
  float C = Ra * Ra * sin(th1 - th2) - Ra * (sin(th1) * L2 + sin(th2) * L1);
  float R = sqrt(A * A + B * B);
  if (abs(C / R) > 1.0) return false;
  th3 = asin(C / R) - atan2(B, A);
  return true;
}

// ─────────────────────────────────────────────
//  TAIL TIP POSITION  (Eqs. 9-10)
// ─────────────────────────────────────────────
void tailTipPosition(float theta_a, float &tipX, float &tipY) {
  if (abs(theta_a) < 0.001) {
    tipX = L_body; tipY = 0.0;
  } else {
    float r = L_body / theta_a;
    tipX = r * sin(theta_a);
    tipY = r * (1.0 - cos(theta_a));
  }
}

// ─────────────────────────────────────────────
//  SWIMMING SPEED ESTIMATE  (Eqs. 14-15)
// ─────────────────────────────────────────────
float estimateSpeed(float theta_a, float theta_a_dot) {
  float tip_speed;
  if (abs(theta_a) < 0.001) {
    tip_speed = L_body * abs(theta_a_dot);
  } else {
    float dY = (L_body / (theta_a * theta_a)) * (sin(theta_a) - theta_a * cos(theta_a));
    tip_speed = abs(dY * theta_a_dot);
  }
  return k_thrust * tip_speed;
}

// ─────────────────────────────────────────────
//  SYMMETRIC MODE  (Eq. 5 / 22)
//  theta1 = theta2 = omega*t → 1-DoF, max thrust
//  Returns: target omega for both motors (rad/s)
// ─────────────────────────────────────────────
float symmetricMode(float omega, float &th3, float &th3_dot, float &v_robot) {
  float th1 = omega * t;
  float th2 = th1;
  if (!forwardKinematics(th1, th2, th3)) {
    Serial.println("[SYM] FK unreachable");
    return omega;
  }
  th3_dot = (th3 - th3_prev) / DT;
  th3_prev = th3;
  float theta_a     = (Rb / d_wire) * th3;
  float theta_a_dot = (Rb / d_wire) * th3_dot;
  v_robot = estimateSpeed(theta_a, theta_a_dot);
  return omega;
}

// ─────────────────────────────────────────────
//  ASYMMETRIC MODE  (Eq. 6 / 23)
//  Motor 1: rotates at omega (propulsion)
//  Motor 2: held at phi by cascaded PID (steering)
//  Returns: target omega for Motor 1 (rad/s)
// ─────────────────────────────────────────────
float asymmetricMode(float omega, float phi,
                     float &th3, float &th3_dot, float &v_robot) {
  float th1 = omega * t;
  float th2 = phi;
  if (!forwardKinematics(th1, th2, th3)) {
    Serial.println("[ASYM] FK unreachable");
    return omega;
  }
  th3_dot = (th3 - th3_prev) / DT;
  th3_prev = th3;
  float theta_a     = (Rb / d_wire) * th3;
  float theta_a_dot = (Rb / d_wire) * th3_dot;
  v_robot = estimateSpeed(theta_a, theta_a_dot);
  return omega;
}

// ─────────────────────────────────────────────
//  LOW-LEVEL MOTOR DRIVE
// ─────────────────────────────────────────────
void driveMotor1(int pwm) {
  if (pwm >= 0) { digitalWrite(M1_IN1, HIGH); digitalWrite(M1_IN2, LOW);  }
  else          { digitalWrite(M1_IN1, LOW);  digitalWrite(M1_IN2, HIGH); pwm = -pwm; }
  analogWrite(M1_ENA, constrain(pwm, 0, 255));
}
void driveMotor2(int pwm) {
  if (pwm >= 0) { digitalWrite(M2_IN1, HIGH); digitalWrite(M2_IN2, LOW);  }
  else          { digitalWrite(M2_IN1, LOW);  digitalWrite(M2_IN2, HIGH); pwm = -pwm; }
  analogWrite(M2_ENA, constrain(pwm, 0, 255));
}

// ─────────────────────────────────────────────
//  SEQUENCE MANAGER
// ─────────────────────────────────────────────
uint8_t updateSequence() {
  if (millis() - stepStart >= SEQUENCE[seqIdx].dur) {
    seqIdx    = (seqIdx + 1) % SEQ_LEN;
    stepStart = millis();
    resetPID(pid1_spd);
    resetPID(pid2_pos);
    resetPID(pid2_spd);
    Serial.print("[SEQ] Step → "); Serial.println(seqIdx);
  }
  return SEQUENCE[seqIdx].mode;
}

// ─────────────────────────────────────────────
//  SETUP
// ─────────────────────────────────────────────
void setup() {
  Serial.begin(115200);
  Serial.println("=== Fish Robot — Full Control System ===");

  pinMode(M1_ENA, OUTPUT); pinMode(M1_IN1, OUTPUT); pinMode(M1_IN2, OUTPUT);
  pinMode(M2_ENA, OUTPUT); pinMode(M2_IN1, OUTPUT); pinMode(M2_IN2, OUTPUT);

  pinMode(ENC1_A, INPUT_PULLUP); pinMode(ENC1_B, INPUT_PULLUP);
  pinMode(ENC2_A, INPUT_PULLUP); pinMode(ENC2_B, INPUT_PULLUP);
  attachInterrupt(digitalPinToInterrupt(ENC1_A), enc1ISR, CHANGE);
  attachInterrupt(digitalPinToInterrupt(ENC2_A), enc2ISR, CHANGE);

  stepStart = millis();
  Serial.println("mode | m1_tgt w | m1_act w | m2_tgt deg | m2_act deg | th3 | theta_a | v_robot");
}

// ─────────────────────────────────────────────
//  MAIN LOOP  (20 Hz)
// ─────────────────────────────────────────────
static unsigned long lastPID = 0;

void loop() {
  unsigned long now = millis();
  if (now - lastPID < PID_INTERVAL_MS) return;
  lastPID = now;

  t = now / 1000.0;
  currentMode = updateSequence();

  // ── Read encoders atomically ──
  noInterrupts();
  long c1 = enc1Count; long c1p = enc1Prev; enc1Prev = c1;
  long c2 = enc2Count; long c2p = enc2Prev; enc2Prev = c2;
  interrupts();

  // Measured velocities (rad/s) from delta counts over DT
  float m1_omega_act = deltaToRadPerSec(c1 - c1p, DT);
  float m2_omega_act = deltaToRadPerSec(c2 - c2p, DT);

  // Measured positions (rad)
  float m2_pos_act = countsToRad(c2);

  // ── Kinematics ──
  float th3 = 0, th3_dot = 0, v_robot = 0;
  float m1_target_omega = 0.0;
  float m2_target_pos   = 0.0;

  if (currentMode == 0) {
    // Symmetric: Motor 1 and Motor 2 both spin at omega
    // Motor 2 position tracks Motor 1's live position
    m1_target_omega = symmetricMode(FORWARD_OMEGA, th3, th3_dot, v_robot);
    m2_target_pos   = countsToRad(c1);   // mirror Motor 1

  } else {
    float phi = (currentMode == 1) ? TURN_THETA2_R : TURN_THETA2_L;
    m1_target_omega = asymmetricMode(TURN_OMEGA, phi, th3, th3_dot, v_robot);
    m2_target_pos   = phi;
  }

  // ══════════════════════════════════════════
  //  MOTOR 1 — SPEED PID
  //  Ensures omega stays constant as the paper assumes.
  // ══════════════════════════════════════════
  float err1 = m1_target_omega - m1_omega_act;
  int pwm1 = computePID(pid1_spd, err1, DT);
  driveMotor1(pwm1);

  // ══════════════════════════════════════════
  //  MOTOR 2 — CASCADED PID
  //
  //  OUTER (position): error_pos (rad) → commanded speed (rad/s)
  //  INNER (speed):    error_spd (rad/s) → PWM
  //
  //  The outer loop tells Motor 2 how fast to move.
  //  The inner loop makes it actually move at that speed
  //  regardless of the elastic tail pushing back.
  // ══════════════════════════════════════════

  // Wrap position error to [-pi, pi]
  float err2_pos = m2_target_pos - m2_pos_act;
  while (err2_pos >  PI) err2_pos -= TWO_PI;
  while (err2_pos < -PI) err2_pos += TWO_PI;

  // Outer loop output = commanded speed, clamped
  float m2_cmd_spd = (float)computePID(pid2_pos, err2_pos, DT);
  m2_cmd_spd = constrain(m2_cmd_spd, -M2_MAX_CMD_SPEED, M2_MAX_CMD_SPEED);

  // Inner loop: speed error → PWM
  float err2_spd = m2_cmd_spd - m2_omega_act;
  int pwm2 = computePID(pid2_spd, err2_spd, DT);
  driveMotor2(pwm2);

  // ── Serial telemetry ──
  float theta_a = (Rb / d_wire) * th3;
  Serial.print(currentMode);                     Serial.print(" | ");
  Serial.print(m1_target_omega, 2);              Serial.print(" | ");
  Serial.print(m1_omega_act, 2);                 Serial.print(" | ");
  Serial.print(m2_target_pos * 180.0 / PI, 1);  Serial.print("deg | ");
  Serial.print(m2_pos_act    * 180.0 / PI, 1);  Serial.print("deg | ");
  Serial.print(th3, 3);                          Serial.print(" | ");
  Serial.print(theta_a, 3);                      Serial.print(" | ");
  Serial.print(v_robot, 2);                      Serial.println(" mm/s");
}
